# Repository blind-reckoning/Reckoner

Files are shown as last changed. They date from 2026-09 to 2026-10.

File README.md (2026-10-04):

<p align="center">
  <picture>
    <source media="(prefers-color-scheme: dark)" srcset="brand/logos/lockup-reversed.svg">
    Blind Reckoning
  </picture>
</p>

<p align="center">
  <strong>Turns press-and-hold motorised blinds into Home Assistant covers.</strong><br>
  One Reckoner per blind, hidden in the wall box behind the buttons you already have.
</p>

<p align="center">
  
  
  
  
  
  
  
</p>

> [!CAUTION]
> **This project switches 230 VAC mains, and its electronics are not isolated from the mains.** There is no transformer: every part of the board, including the microcontroller, the LED and the programming pads, sits at mains voltage whenever it is connected.
>
> A mistake while building, testing, flashing or installing it can **kill you** or **start a fire inside your wall**. Read the whole [Safety](#safety) section before you build, power or install anything.
>
> **If you are not qualified to work on mains wiring, do not build or install this.** Read it, learn from it, but leave the wall to an electrician.

## What it does

Motorised blinds with press-and-hold buttons have no idea where they are. The Reckoner sits in the wall box between those buttons and the blind motor, and adds what the buttons can't.

- **Keeps your buttons working, with or without Wi-Fi.** One press runs the blind all the way up or down. Another press while it is moving stops it.
- **For Home Assistant.** The blind appears as a cover: open, close, stop, set position and report position.
- **Always knows where the blind is.** There is no position sensor. It works the position out by **dead reckoning**, the way navigators did before GPS: from a known starting point, the calibrated time for a full stroke and the time elapsed.
- **Takes a fix at every end.** When the blind reaches fully open or fully closed, the motor's own limit switch cuts its current. The Reckoner sees that drop and takes a **fix** (position confirmed), which clears any **drift** (timing error built up since the last fix).
- **Keeps its position through power cuts.** It notices mains loss within one cycle and saves the position on the energy left in its capacitors.
- **Fits behind the switches.** The board is 70 × 54.5 mm, sized for an Italian 503 wall box.

Positions are whole percent: 0% is closed and 100% is open, matching Home Assistant.

## How it works

Every movement now goes through the Reckoner, so the blind can't move without it knowing.

| Block | Main parts | What it does |
|---|---|---|
| Mains input | 2 A slow-blow fuse, 275 VAC varistor | Protects the board and the wall wiring; circuit ground is mains L after the fuse |
| Off-line 5 V supply | LNK3206D high-side buck | Makes 5 V straight from the mains, with no transformer, and keeps running for at least 100 ms after a power cut |
| 3.3 V regulator | AP2112K-3.3 | Clean 3.3 V for the radio and the metering chip |
| Microcontroller | ESP32-C6-MINI-1 | Wi-Fi 6, Bluetooth LE and Thread; runs the dead-reckoning logic |
| Metering | HLW8110, 10 mΩ shunt | Measures motor current (to detect the ends) and mains voltage |
| Motor relays | HF46F-G on/off, G5Q-14 changeover | Switches the motor, interlocked in hardware |
| Button and mains sense | resistor dividers, BAT54S clamps | Reads the wall buttons and every mains cycle, without optocouplers |
| Programming pads | 13 test pads | First flash only, with mains disconnected; updates after that go over the air |

<p align="center">
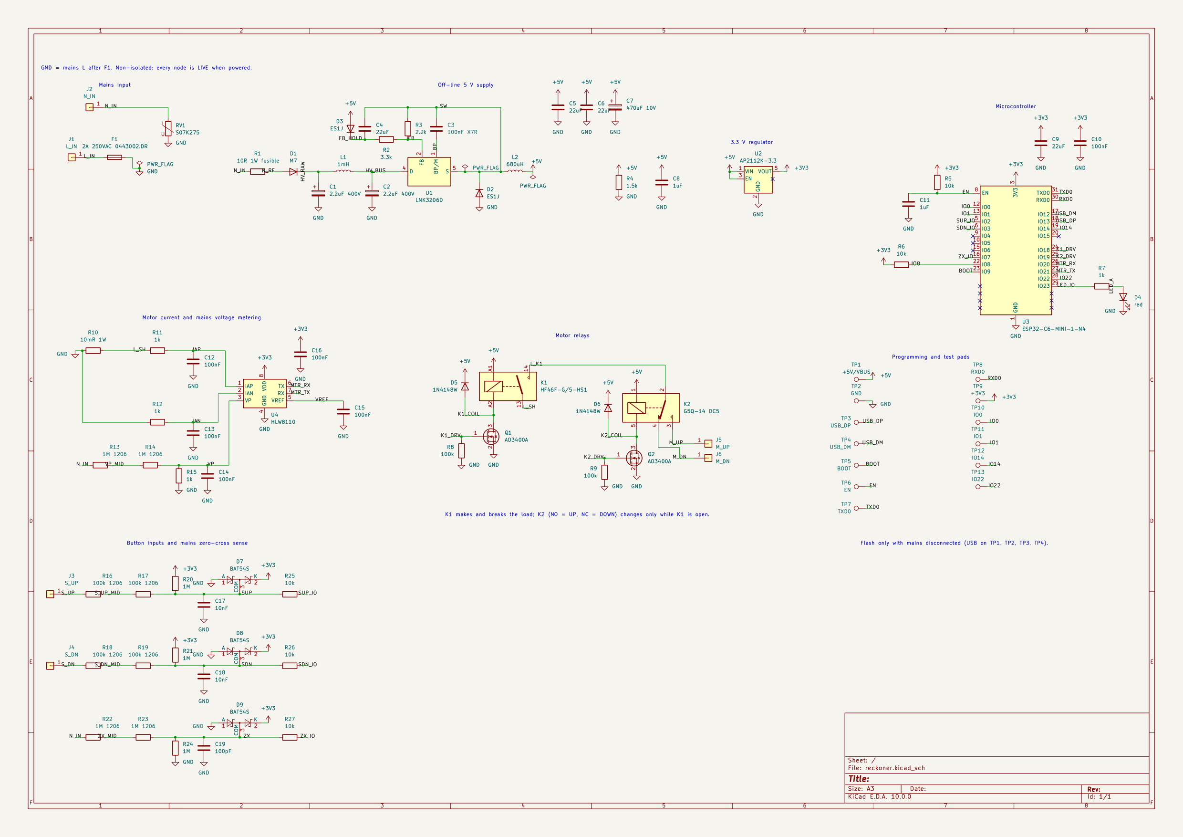
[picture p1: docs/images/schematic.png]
The full Reckoner schematic
  
</p>

### The interlock

<p align="center">
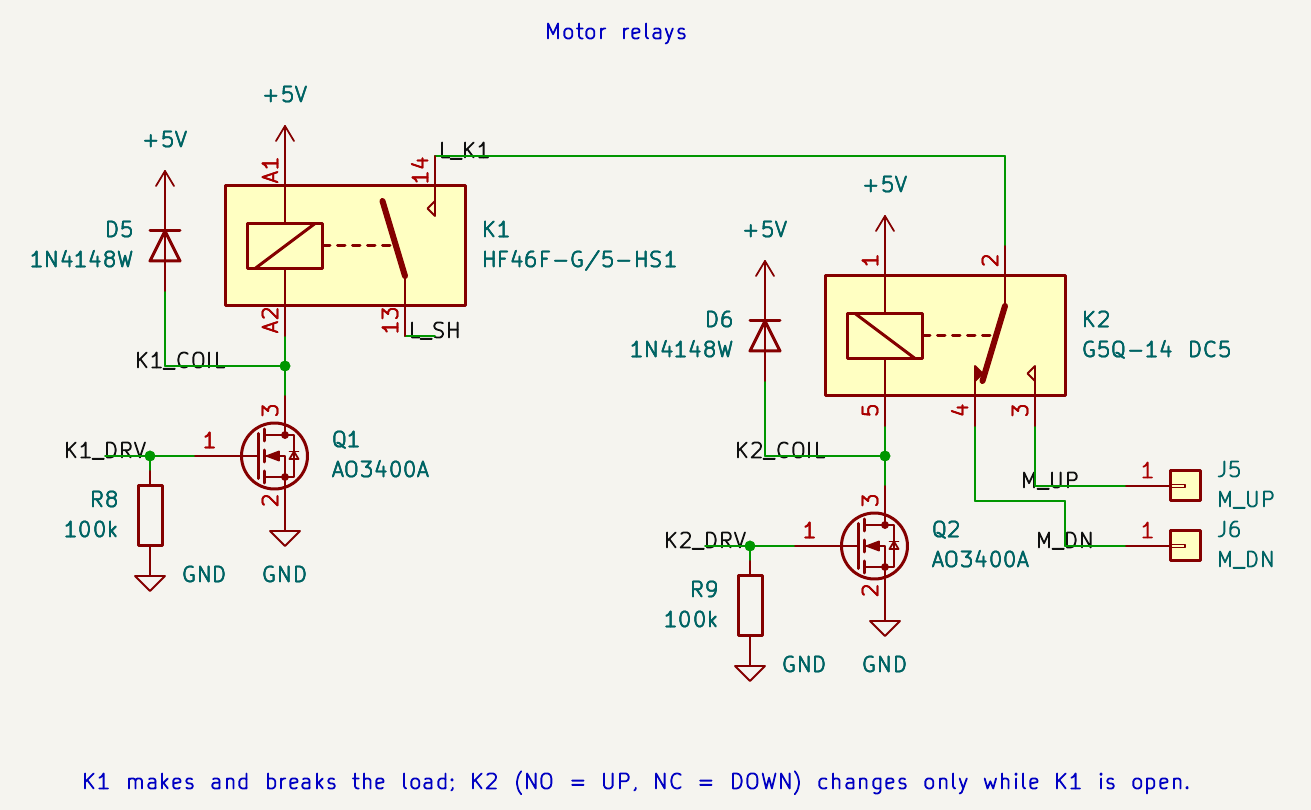
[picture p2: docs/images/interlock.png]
Motor relay block: K1 on/off feeding K2 changeover
  
</p>

K1 is the only relay that switches the motor on and off. K2 only chooses the direction, and its common contact is fed **through** K1. A changeover contact can only ever touch one side, so **up and down can never be live at the same time**: not with a firmware bug, not with a crash, not even with a welded contact.

| K1 | K2 | Motor |
|---|---|---|
| off | either | stopped |
| on | off | down |
| on | on | up |

The firmware sets K2 first and then closes K1, and opens K1 before releasing K2, so K2 never switches under load. Both relay drivers are held off by hardware through reset, boot, crashes and flashing.

### The board

<p align="center">
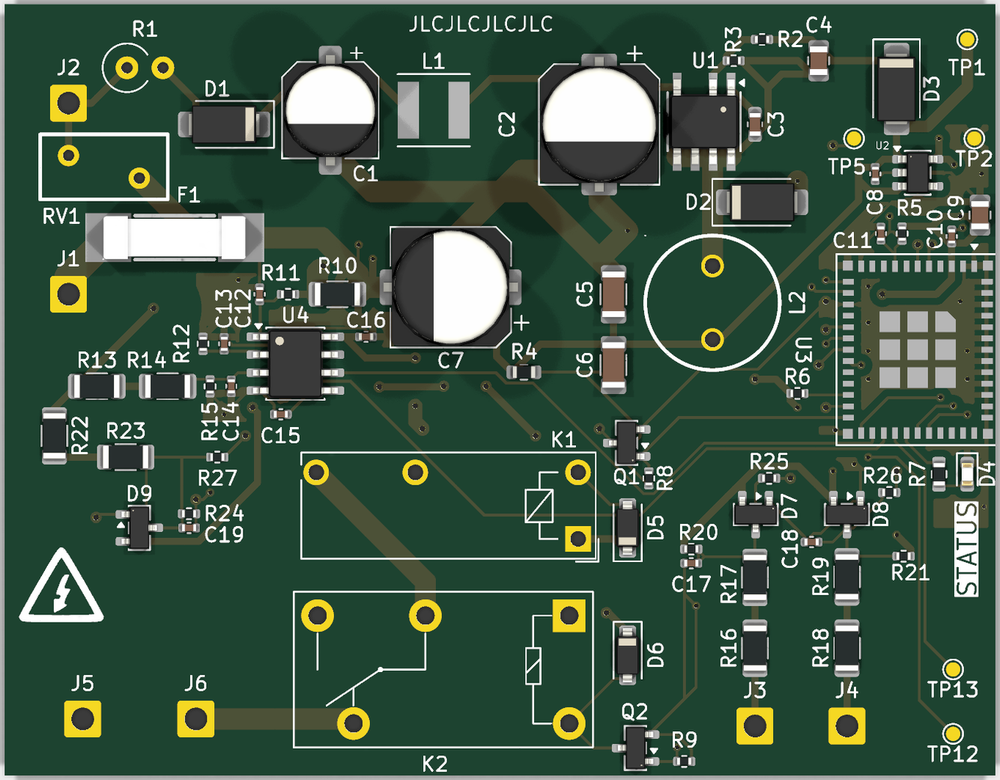
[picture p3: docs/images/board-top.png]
The routed Reckoner, top side
  
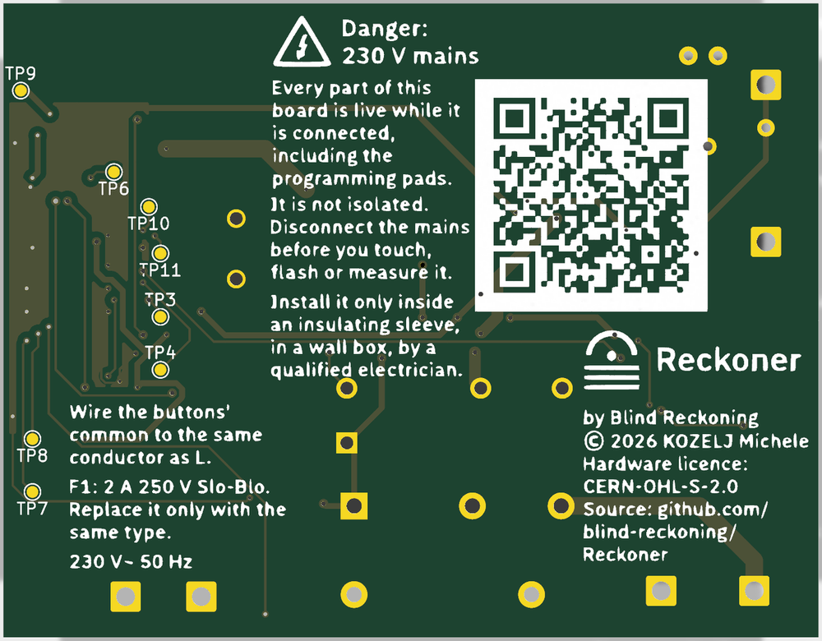
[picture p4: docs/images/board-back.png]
The Reckoner, back side: mains warnings, licence and a QR code to this repository
  
</p>

The board is 70 × 54.5 mm on two layers, placed and routed by hand. Custom design rules keep the mains nodes 3 to 5 mm apart, and 5 mm around the motor wires. The back carries the mains warnings, the licence and a QR code to this repository. The Gerbers, drill and placement files for JLCPCB are in [`PCB/production/`](PCB/production/).

## Safety

### Why this board is more dangerous than most

> [!WARNING]
> **There is no low-voltage side.** Circuit ground is **mains live (L)**. The ESP32, its antenna, the LED, the MOSFETs, the test pads and every copper trace sit at 230 VAC relative to earth whenever L and N are connected. There is no protective earth connection, so all protection from shock comes from the enclosure.

- **"Off" is not safe.** The board is powered as long as L and N are connected. A blind that is stopped, relays that are open or a "power off" in an app change nothing. Only isolating the circuit at the breaker does.
- **The motor wires are dangerous even when idle.** J5 and J6 connect to neutral through the motor windings when the relays are open. While the motor runs, its run capacitor puts about **460 VAC** between the up and down wires.
- **It can stay charged after you unplug it.** The two 400 V capacitors (C1 and C2) can hold a dangerous charge after mains is removed. Measure across them before you touch a board that has been powered.

### Never

> [!CAUTION]
> - **Never connect a USB cable, USB-serial adapter, debugger or laptop while the board is connected to mains.** A computer's USB ground is usually tied to earth through its charger. Joining it to this board's ground, which is mains L, shorts L to earth through your cable and your computer, and can make the computer's metal parts live.
> - **Never use a grounded oscilloscope probe or a mains-powered instrument on a live board.** Same reason, same result.
> - **Never touch the board while it is connected to mains**, not even "just the logic side". There is no logic side. There is only the death side!
> - **Never power it without an insulating enclosure**, and never mount it in a metal box or anywhere it can touch other conductors.
> - **Never work on live mains alone.** Always have a person capable, trained and willing of providing first aid.

### Before you install

1. **Get a qualified electrician.** In many countries, Italy included, work on fixed household wiring must be done by a qualified installer. An uncertified device in your wiring may also affect your home insurance. Check your local rules.
2. **Isolate and prove dead.** Switch off the circuit at the breaker, lock it off, and check with a voltage tester that you have just checked on a known live source. Check the tester again afterwards.
3. **Check the upstream protection.** The circuit must have a breaker of 16 A or less (with at least 6 kA breaking capacity) and a 30 mA RCD. The board's fuse handles overloads only: with its 50 A breaking capacity it relies on the house breaker to clear a direct short.
4. **Wire it exactly as labelled.**
   - J1 goes to live (L) and J2 to neutral (N). Swapping them is not supported.
   - The wall buttons' common must be on the **same L conductor** as J1.
   - J3 and J4 go to the up and down button outputs, and J5 and J6 to the motor's up and down wires.
   - The motor's neutral stays on house N in the box; it never goes to the board.
5. **Use the right materials.** The leads are 0.75 mm² H05V-K wire rated 450/750 V. Join them with lever connectors rated for the circuit, and keep the insulated board clear of the other cables in the box.
6. **Check the motor.** It must be a 230 VAC capacitor-run tubular motor of about 1 A, with two direction wires and **its own end-of-travel limit switches**. The Reckoner relies on those switches to stop at the ends. Don't connect anything larger: the direction relay is rated 3 A at 250 VAC.

### Flashing and bench testing

- **Flash only with mains disconnected at the source**, never just switched off at the wall. The first flash uses the USB pads TP1 to TP4. Short TP5 (BOOT) to GND during reset to enter download mode. After that, updates go over the air. The first-flash procedure hasn't been tried on hardware yet.
- **Live testing belongs on an isolated bench:**
  - power it through an isolation transformer;
  - use a current-limited supply, such as a series-lamp limiter, for the first power-up;
  - keep a clear shield in front of the board and your hands away from it;
  - measure only with isolated or differential probes.
- **An isolation transformer doesn't make the board safe to touch.** It only removes the earth reference.

### What the board does to protect you, and what it doesn't

| It does | It doesn't |
|---|---|
| A 2 A slow-blow fuse on L, a 10 Ω fusible resistor in front of the supply and a 275 VAC varistor against surges | Isolate anything: there is no transformer, no earth and no touch protection on the board |
| Have a hardware interlock: up and down can never both be live | Clear a direct short by itself: that is the house breaker's job |
| Have relays that default to off through reset, boot, crashes and flashing | Make "off" safe: the board is live while L and N are connected |
| Have button inputs that tolerate a common wired to N (at most 1.6 mA flows, and the firmware can flag it) | Replace an enclosure, an RCD or a qualified installer |
| Have a layout that keeps mains nodes 3 to 5 mm apart, and 5 mm around the motor wires, except between a part's own pins | Carry any certification: no CE marking, no UL listing, no lab testing |

### Disclaimer

> [!IMPORTANT]
> Blind Reckoning is a hobby prototype I built for Hack Club Half Life. It is **not a certified product** and has **not been tested by any laboratory**. Everything in this repository is provided as is, without warranty of any kind.
>
> **If you build, flash, test or install a Reckoner, you do so entirely at your own risk.** The authors accept no responsibility for injury, death, fire or damage to property caused by using anything in this repository.
>
> The **Blind Reckoning** "brand" is just a game. Please don not take it too seriously ;)

## Project status

| Stage | State |
|---|---|
| Requirements and architecture | done |
| Parts list (`BOM/bom.csv`, JLCPCB/LCSC parts) | done |
| Schematic: 86 parts, 51 nets, 0 ERC errors | done |
| PCB layout: 70 × 54.5 mm, two layers | done |
| Production files for JLCPCB (`PCB/production/`) | done |
| Order costed: 5 PCBs, a stencil and parts for one board (`bom.csv`) | done |
| Ordering boards and parts | next |
| Enclosure | not started |
| Firmware | not started |

## Repository

```
PCB/            KiCad 10 project: schematic, board, custom symbols and footprints
PCB/production/ Gerbers, drill and placement files for JLCPCB
CAD/            enclosure and 3D assembly (to come)
Firmware/       firmware (to come)
brand/          logos, colours and fonts
docs/images/    images used in this README
BOM/            bill of materials (bom.csv, ready for JLCPCB assembly), ordering lists and supplier quotes
bom.csv         order cost: PCBs, stencil, parts, shipping and taxes
LICENSE         hardware licence: CERN-OHL-S-2.0
LICENSE-DOCS    documentation licence: CC BY-SA 4.0
```

## Licence

Blind Reckoning is open hardware. You may study, build, modify, share and sell it under these terms:

| What | Licence | Full text |
|---|---|---|
| **Hardware:** everything in `PCB/` and `CAD/`, and `BOM/bom.csv` | CERN Open Hardware Licence version 2, strongly reciprocal (**CERN-OHL-S-2.0**) | [`LICENSE`](LICENSE) |
| **Documentation:** this README and everything in `docs/` | Creative Commons Attribution-ShareAlike 4.0 International (**CC BY-SA 4.0**) | [`LICENSE-DOCS`](LICENSE-DOCS) |
| **Firmware** | Not written yet; its licence will be chosen when it is. | |

**These licences apply retroactively.** They cover every version of this repository, including all commits made before the licence files were added on 2 October 2026. Any copy of the hardware or documentation you obtained from this repository, from any commit, is licensed under the terms above as if the licence files had been there from the first commit.

**Strongly reciprocal** means that if you share a modified Reckoner design, or make and sell boards based on one, you must publish your modified design under the same licence. For a mains device, this keeps every change, including the safety-relevant ones, open to review.

Hardware notice:

```
Copyright 2026 KOZELJ Michele

This source describes Open Hardware and is licensed under the CERN-OHL-S v2.

You may redistribute and modify this source and make products using it under
the terms of the CERN-OHL-S v2 (https://ohwr.org/cern_ohl_s_v2.txt).

This source is distributed WITHOUT ANY EXPRESS OR IMPLIED WARRANTY, INCLUDING
OF MERCHANTABILITY, SATISFACTORY QUALITY AND FITNESS FOR A PARTICULAR PURPOSE.
Please see the CERN-OHL-S v2 for applicable conditions.

Source location: https://github.com/blind-reckoning/Reckoner

As per CERN-OHL-S v2 section 4, should You produce hardware based on this
source, You must where practicable maintain the Source Location visible on
the circuit board or enclosure of the Reckoner or other products you make
using this source.
```

Not covered by these licences:

- **The Blind Reckoning name and logos** (`brand/logos/`, `brand/symbols/`) are not licensed for reuse. Modified or cloned hardware must use its own name and mark. You may say it is "for Blind Reckoning" or "compatible with Blind Reckoning" (see the [brand book](brand/README.md)).
- **The fonts** in `brand/fonts/` (IBM Plex Sans, IBM Plex Mono, Young Serif) belong to their authors and are distributed under the SIL Open Font License 1.1. Their licence files are next to them.
- **KiCad library symbols and footprints** used in the design are under KiCad's library licence (CC BY-SA 4.0 with an exception for designs that use them), so they don't change the licence of the Reckoner design.

## Built for

[Hack Club Half Life](https://halflife.hackclub.com), 2026.

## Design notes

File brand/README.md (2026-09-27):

# Blind Reckoning brand

The brand book for Blind Reckoning. Follow it for any UI, docs, README copy, packaging or user-facing strings.

## Files in this folder

- `tokens.css`: every color, spacing, radius and shadow token as a CSS custom property (`var(--chart)`, `var(--space-4)`), both themes, the `@font-face` rules and `.type-*` classes for the text styles. Link it and use the variables; never hard-code a hex value. Set `data-theme="night-watch"` on `<html>` to force dark, `data-theme="chart"` to force light; otherwise it follows the system setting.
- `tokens.json`: the same tokens as data, with a usage note on each.
- `fonts/`: Young Serif, IBM Plex Sans and IBM Plex Mono (SIL Open Font License).
- `logos/`: the mark, lockup and wordmark as outlined SVGs. Never redraw them.
- `symbols/`: the dead-reckoning and fix symbols.

Token names below (`chart`, `brass`, `sea`…) are the CSS variables without the `--`.

Blind Reckoning turns press-and-hold motorised blinds into Home Assistant covers. It cannot see where a blind is, so it works it out the way navigators did before GPS: from a known starting point, a known speed and the time elapsed. When the blind reaches fully open or fully closed, it takes a **fix** and clears any drift. The identity comes from the chart table: chart paper, navy ink, brass instruments and a red course line.

## Name

- Write **Blind Reckoning**: two words, both capitalised. Never "BlindReckoning", "Blind-Reckoning" or "BR" in prose.
- In code: `blind-reckoning` for the repository and packages, `blind_reckoning` for the Home Assistant integration domain.
- The hardware unit is a **Reckoner**: "fit one Reckoner per blind".
- Say "for Home Assistant". Never put "Home Assistant" in the name, the mark or a product title.
- Other people's work says "for Blind Reckoning" or "compatible with Blind Reckoning". Forks and clones that change the firmware or hardware use their own name and mark.

## Voice

Plain, precise, quietly nautical. Say what the device is doing in one sentence, then stop.

- Use navigation words only where they mean exactly the thing (see Vocabulary). Never as decoration: no "ahoy", pirates, anchors or rope.
- Sentence case everywhere except the `label` style. No exclamation marks, no emoji.
- Talk to "you"; the device is "it".
- Seconds take one decimal and a space before the unit: "23.4 s". Positions are whole percent, 0% closed and 100% open, matching Home Assistant.

Write like this:

> Took a fix at fully open. Corrected 0.8 s of drift.

> Heave the log: run the blind fully down, then press Stop the moment it lands.

> Position is estimated. It is confirmed the next time the blind reaches an end.

Not like this: "Arr, yer blinds be smart now!", "Revolutionary AI-powered shading."

## Vocabulary

| Term | Means | In the UI |
| --- | --- | --- |
| Fix | Position confirmed at an endstop | "Last fix: fully open, 2 h ago" |
| Drift | Timing error built up since the last fix | "Drift ±1.2 s" |
| DR position | Position estimated from elapsed time | "41% (estimated)" |
| Heave the log | The calibration run that times a full stroke | "Heave the log" button in setup |
| Heading | Direction of travel | "Heading up" |

The first time a term appears on a screen, put the plain meaning beside it.

## Logo

The mark is a semicircle and dot, the navigator's plotting symbol for a dead-reckoning position, rising over three slats. It also reads as a sun on the horizon, which is what blinds are for.

- `mark.svg` (brass arc, ink slats) on `chart` and `chart-raised`.
- `mark-reversed.svg` on the Night watch `chart` and on any `deep` fill.
- `mark-ink.svg` for one-colour print; `mark-white.svg` for PCB silkscreen and laser etching.
- `lockup.svg` / `lockup-reversed.svg` where the name must travel with the mark (README header, packaging, the device web page). `wordmark.svg` alone only where the mark already appears nearby.
- Clear space: a quarter of the mark's height on every side. Minimum size: mark 24 px (6 mm printed), lockup 120 px wide.
- Don't recolour it beyond these versions, rotate it, outline it, add compass needles, ships or anchors, or retype the wordmark in another face.

## Color

Two themes share every token name: **Chart** by day and **Night watch** by night.

- Ground is `chart`; panels are `chart-raised`; text is `ink`, secondary text `ink-muted`. `rule` is for decorative dividers only.
- `brass` is the identity: the mark, highlights and the drift state. Keep it to roughly a tenth of any screen. Brass words use `brass-text`, on `brass-soft` when tinted.
- `deep` with `on-deep` for the header band, hero panels and the primary button.
- States: a fix is `sea` with the Fix symbol; drift is `brass` with the word "drift"; a fault or Stop is `course`. Never carry a state by colour alone.
- Keyboard focus is the `focus-ring` shadow: a 2 px gap in the ground colour, then 2 px of solid `sea`.

## Type

- `display` (Young Serif) for page titles and the wordmark only. Never in device UI, never below 24 px.
- `heading`, `body` and `label` (IBM Plex Sans) for everything people read. `label` is set in capitals.
- `reading` (IBM Plex Mono) for the instrument readout: current position and travel time. `code` for entity IDs, YAML and firmware values.
- All three families are under the SIL Open Font License, so the firmware's web page can bundle them.

## Symbols

- `dr-position.svg`, a semicircle and dot on a baseline: position estimated by timing.
- `fix.svg`, a circle and dot: position confirmed at an endstop.
- Both are 24 px with a 2 px stroke, drawn in `ink`; always set a word beside them.
- For every other icon use Material Design Icons (`mdi:blinds`, `mdi:arrow-up`, `mdi:stop`), the set Home Assistant already uses, so the device page and the dashboard match.

## Imagery

Line drawings on chart paper: timing diagrams, the slat stack, a plotted course from open to closed. Photos show real installs in daylight and the hardware on a workbench. No stock oceans, ships or brass compasses as decoration; the metaphor lives in the words and the mark.

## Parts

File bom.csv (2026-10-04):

Item | Quantity | Supplier | Price (USD) | Note
Bill of materials (reference only) | 1 | N/A | 0.00 | The per-part BOM is BOM/bom.csv. Orders: BOM/bom-lcsc.csv (LCSC) and BOM/bom-digikey.csv (Digi-Key). Quote screenshots are in BOM/.
PCB: 2 layers, 70 × 54.5 mm, 1.6 mm, green, lead-free HASL | 1 | JLCPCB | 6.25 | 5 units included
SMT stencil, top side, with frame | 1 | JLCPCB | 16.75
LCSC parts | 1 | LCSC | 29.24 | Order quantities include LCSC minimum orders.
DigiKey parts | 1 | Digi-Key | 4.77
Shipping and taxes |  | All | 89.74 | JLCPCB $24.28 (shipping $34.28 - $10.00 coupon). LCSC $30.17 (shipping $12.88 + tax $20.34 - $3.05 of discounts). Digi-Key $35.29 (€25.00 shipping + €6.44 VAT).
Total |  |  | 146.75 | Items $57.01, shipping and taxes $89.74.

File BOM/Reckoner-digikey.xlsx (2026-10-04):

Country of Origin may be different at time of shipment.
The HTSUS and ECCN information shown is for informational purposes only and is not a representation or warranty as to the accuracy or reliability of these classifications. All information is provided "as is" and is subject to change without notice. Any use made of the information provided is without recourse to Digi-Key and at the user's risk.
Index | Manufacturer Part Number | Manufacturer Name | Description | Lead Time | Availability | Stock Status | Attrition % | Requested Quantity 1 | Pack Quantity 1 | Pack Type 1 | Digi-Key Part Number 1 | Unit Price 1 | Extended Price 1 | Minimum Order Quantity 1 | Customer Reference | Requested Part Number | Lead Weeks | Datasheet | Reference Designator | US Import Tariff | Note | Part Status | RoHS Status | REACH Status | Moisture Sensitivity Level (MSL) | ECCN | HTSUS | Country of Origin | Environmental Information | Original Part numbers | Unit of Measure | Image | Product Notes
1 |  |  |  |  |  |  |  |  |  |  |  |  |  |  |  | Digi-Key Part Number | N/A |  | Reference Designator |  | Note |  | - | - |  | - | - | - |  | Digi-Key Part Number |  |  | This entry does not match a product carried by DigiKey and cannot be quoted.
2 | ESP32-C6-MINI-1-N4 | Espressif Systems | RF TXRX MOD BT WIFI PCB TH SMD |  | 190 | In Stock |  | 1 | 1 | Cut Tape (CT) | 1965-ESP32-C6-MINI-1-N4CT-ND | 3.98000 | €3.98 | 1 |  | 1965-ESP32-C6-MINI-1-N4CT-ND | 8 | https://www.espressif.com/sites/default/files/documentation/esp32-c6-mini-1_mini-1u_datasheet_en.pdf | U3 | N/A | Same part; backordered at LCSC. | Active | Unknown |  | 3 (168 Hours) | 5A992C SC | 8517.62.0090 | Taiwan |  | 1965-ESP32-C6-MINI-1-N4CT-ND | Each | https://mm.digikey.com/Volume0/opasdata/d220001/medias/images/4908/MFG_ESP32-C6-MINI-1-N4.jpg
3 | RC0402FR-071KL | YAGEO | RES 1K OHM 1% 1/16W 0402 |  | 4,297,806 | In Stock |  | 3 | 3 | Cut Tape (CT) | 311-1.00KLRCT-ND | 0.09000 | €0.27 | 1 |  | 311-1.00KLRCT-ND | 22 | https://yageogroup.com/content/datasheet/asset/file/PYU-RC_GROUP_51_ROHS_L | R11,R12,R15 | N/A | Same spec as the UNI-ROYAL part, which is backordered at LCSC. | Active | ROHS3 Compliant | REACH Unaffected | 1 (Unlimited) | EAR99 | 8533.21.0030 | Taiwan | https://www.yageogroup.com/content/Resource%20Library/Product%20Environmental%20Compliance/RoHS_Compliance_YAGEO.pdf | 311-1.00KLRCT-ND | Each | https://mm.digikey.com/Volume0/opasdata/d220001/derivates/6/003/121/213/cut-tape-render_web%28640x640%29.jpg

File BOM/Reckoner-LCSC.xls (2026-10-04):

Reckoner-LCSC |  |  |  |  |  |  |  |  |  | LCSC BOM Quotation
 |  |  |  |  |  |  |  |  |  | BOM Date Created：04/10/26 20:34:16 |  |  |  | BOM Export Date: 04/10/26 20:36:48 |  |  |  | The matching result is a real-time query result, availability and prices may fluctuate. Backorder items are estimated prices for your reference, please submit "Create Quote" to get the real price. All information is provided "as is" and is subject to change without notice. Any use made of the information provided is without recourse to LCSC and at the user's risk.
 |  |  |  |  |  |  |  |  |  | EST TOTAL :$29.19 |  |  |  | Website：https://www.lcsc.com/bom | https://www.lcsc.com/bom | https://www.lcsc.com/bom | https://www.lcsc.com/bom
Uploaded data |  |  |  |  |  |  |  |  |  | LCSC Matching Results
LCSC# | Mfr. | Mrf# | Description | Package | Value | Customer Part Number | Quantity | Target Price(USD) | Target Lead Time(Business Days) | Mrf# | Mfr. | Order Qty. | Unit Price(USD) | Ext.Price(USD) | LCSC# | Package | Min | Mult | SPQ | Availability | Stock Status | Customer Notes | Description | Matched status | Product Link
C187538 | Littelfuse | 0443002.DR | Littelfuse 0443002.DR, 2 A Slo-Blo | FUSE-SMD_L10.1-W3.1 |  | - | 1 |  |  | 0443002.DR | Littelfuse | 1 | 0.8063 | 0.81 | C187538 | SMD,10.1x3.1mm | 1 | 1 | 1500 | 1892 | In Stock |  | 2A 250V Fuse Surface Mount 10.1x3.1mm | Exact Matches | https://www.lcsc.com/product-detail/C187538.html
C1527389 | TDK | B72207S2271K101 | TDK B72207S2271K101 (S07K275) | RES-TH_L9.0-W4.6-P5.00-D0.6-S1.60 |  | - | 1 |  |  | B72207S2271K101 | TDK | 5 | 0.0815 | 0.41 | C1527389 | Through Hole | 5 | 5 | 1000 | 2570 | In Stock |  | 710V 350V 275V 430V Through Hole Varistors, MOVs RoHS | Exact Matches | https://www.lcsc.com/product-detail/C1527389.html
C145951 | CCO(Chian Chia Elec) | FR1WS-10Ω±5% T | FR1WS 10 Ω fusible | R_Axial_DIN0309_L9.0mm_D3.2mm_P2.54mm_Vertical |  | - | 1 |  |  | FR1WS-10Ω±5% T | CCO(Chian Chia Elec) | 20 | 0.0373 | 0.75 | C145951 | Through Hole,D3.2xL9mm | 20 | 20 | 2000 | 3100 | In Stock |  | 10Ω 1W 250V Fuse Resistor ±200ppm/℃ ±5% Through Hole,D3.2xL9mm Through Hole Resistors RoHS | Exact Matches | https://www.lcsc.com/product-detail/C145951.html
C95872 | MDD(Microdiode Semiconductor) | M7 | M7 | D_SMA |  | - | 1 |  |  | M7 | MDD(Microdiode Semiconductor) | 100 | 0.0103 | 1.03 | C95872 | SMA(DO-214AC) | 100 | 100 | 5000 | 1908900 | In Stock |  | Diode Independent 1kV 1A Surface Mount SMA(DO-214AC) | Exact Matches | https://www.lcsc.com/product-detail/C95872.html
C48970947 | Honor Elec | RYUD400V2.2UF6*10 | 2.2 µF, RYUD400V2.2UF6*10 | CP_Elec_6.3x9.9 |  | - | 1 |  |  | RYUD400V2.2UF6*10 | Honor Elec | 10 | 0.0797 | 0.80 | C48970947 | SMD,D6.3xL10.2mm | 10 | 10 | 700 | 620 | In Stock |  | 400V ±20% 2.2uF SMD,D6.3xL10.2mm Aluminum Electrolytic Capacitors RoHS | Exact Matches | https://www.lcsc.com/product-detail/C48970947.html
C33129636 | FOLLON | EFVD400ADA3R9M08B0 | 3.9 µF, FOLLON EFVD400ADA3R9M08B0 | CP_Elec_8x10 |  | - | 1 |  |  | EFVD400ADA3R9M08B0 | FOLLON | 5 | 0.1372 | 0.69 | C33129636 | SMD,D8xL10.5mm | 5 | 5 | 500 | 440 | In Stock |  | 3.9uF ±20% 400V Aluminum Electrolytic Capacitors | Exact Matches | https://www.lcsc.com/product-detail/C33129636.html
C5339706 | XR | XRNR5040-1mH/M | 1 mH, XRNR5040-1mH/M | L_Taiyo-Yuden_NR-50xx |  | - | 1 |  |  | XRNR5040-1mH/M | XR | 10 | 0.0589 | 0.59 | C5339706 | SMD,5x5mm | 10 | 10 | 1500 | 630 | In Stock |  | 250mA 1mH ±20% 6.2Ω 250mA Magnetic Shielded Inductor SMD,5x5mm Fixed Inductors | Exact Matches | https://www.lcsc.com/product-detail/C5339706.html
C2987730 | POWER INTEGRATIONS | LNK3206D-TL | LNK3206D-TL | PowerIntegrations_SO-8C |  | - | 1 |  |  | LNK3206D-TL | POWER INTEGRATIONS | 1 | 1.0874 | 1.09 | C2987730 | SO-7 | 1 | 1 | 2500 | 430 | In Stock |  | 360mA 66kHz 725V Buck-Boost SO-7 AC DC Converters, Offline Switchers RoHS | Exact Matches | https://www.lcsc.com/product-detail/C2987730.html
C14663 | YAGEO | CC0603KRX7R9BB104 | 100 nF X7R | C_0603_1608Metric |  | - | 1 |  |  | CC0603KRX7R9BB104 | YAGEO | 50 | 0.0124 | 0.62 | C14663 | 0603 | 50 | 50 | 4000 | 5108800 | In Stock |  | 100nF ±10% 50V Ceramic Capacitor X7R 0603 | Exact Matches | https://www.lcsc.com/product-detail/C14663.html
C86560 | MCC | ES1J-LTP | ES1J-LTP | D_SMA |  | - | 2 |  |  | ES1J-LTP | MCC | 20 | 0.0511 | 1.02 | C86560 | SMA(DO-214AC) | 20 | 20 | 5000 | 10040 | In Stock |  | 35ns 600V 1.7V@1A 1A SMA(DO-214AC) Single Diodes RoHS | Exact Matches | https://www.lcsc.com/product-detail/C86560.html
C2924238 | PROD Tech | PDPTAT0810-681K | 680 µH, PDPTAT0810-681K | IND-TH_BD9.5-P5.20-D0.6 |  | - | 1 |  |  | PDPTAT0810-681K | PROD Tech | 5 | 0.1168 | 0.58 | C2924238 | Through Hole,D9.5xL12mm | 5 | 5 | 250 | 2345 | In Stock |  | 350mA 680uH ±10% 800mA 910mΩ Drum-core inductor Through Hole,D9.5xL12mm Fixed Inductors | Exact Matches | https://www.lcsc.com/product-detail/C2924238.html
C45783 | Samsung Electro-Mechanics | CL21A226MAQNNNE | 22 µF X5R | C_0805_2012Metric |  | - | 2 |  |  | CL21A226MAQNNNE | Samsung Electro-Mechanics | 20 | 0.2222 | 4.44 | C45783 | 0805 | 20 | 20 | 2000 | 1105400 | In Stock |  | 22uF ±20% 25V Ceramic Capacitor X5R 0805 | Exact Matches | https://www.lcsc.com/product-detail/C45783.html
C25890 | UNI-ROYAL | 0402WGF3301TCE | 3.3 kΩ 1 % | R_0402_1005Metric |  | - | 1 |  |  | 0402WGF3301TCE | UNI-ROYAL | 100 | 0.0036 | 0.36 | C25890 | 0402 | 100 | 100 | 10000 | 1148200 | In Stock |  | 3.3kΩ ±1% 62.5mW 0402 Thick Film Resistor | Exact Matches | https://www.lcsc.com/product-detail/C25890.html
C25879 | UNI-ROYAL | 0402WGF2201TCE | 2.2 kΩ 1 % | R_0402_1005Metric |  | - | 1 |  |  | 0402WGF2201TCE | UNI-ROYAL | 100 | 0.0013 | 0.13 | C25879 | 0402 | 100 | 100 | 10000 | 744800 | In Stock |  | 2.2kΩ ±1% 62.5mW 0402 Thick Film Resistor | Exact Matches | https://www.lcsc.com/product-detail/C25879.html
C12891 | Samsung Electro-Mechanics | CL31A226KAHNNNE | 22 µF X5R | C_1206_3216Metric |  | - | 2 |  |  | CL31A226KAHNNNE | Samsung Electro-Mechanics | 20 | 0.1751 | 3.50 | C12891 | 1206 | 20 | 20 | 2000 | 7520 | In Stock |  | 22uF ±10% 25V Ceramic Capacitor X5R 1206 | Exact Matches | https://www.lcsc.com/product-detail/C12891.html
C2693598 | SAMYOUNG | BXJ10V470UF8*10 | 470 µF, BXJ10V470UF8*10 | CP_Elec_8x10 |  | - | 1 |  |  | BXJ10V470UF8*10 | SAMYOUNG | 5 | 0.2370 | 1.19 | C2693598 | SMD,D8xL10mm | 5 | 5 | 500 | 375 | In Stock |  | 470uF ±20% 10V Aluminum Electrolytic Capacitors 5000hrs@105℃ | Exact Matches | https://www.lcsc.com/product-detail/C2693598.html
C22843 | UNI-ROYAL | 0603WAF1501T5E | 1.5 kΩ 1 % | R_0603_1608Metric |  | - | 1 |  |  | 0603WAF1501T5E | UNI-ROYAL | 100 | 0.0020 | 0.20 | C22843 | 0603 | 100 | 100 | 5000 | 3638900 | In Stock |  | 1.5kΩ ±1% 100mW 0603 Thick Film Resistor | Exact Matches | https://www.lcsc.com/product-detail/C22843.html
C51118 | DIODES | AP2112K-3.3TRG1 | AP2112K-3.3TRG1 | SOT-23-5 |  | - | 1 |  |  | AP2112K-3.3TRG1 | DIODES | 5 | 0.1726 | 0.86 | C51118 | SOT-25-5 | 5 | 5 | 3000 | 38230 | In Stock |  | 3.3V Positive Fixed SOT-25-5 Voltage Regulators - Linear, Low Drop Out (LDO) Regulators RoHS | Exact Matches | https://www.lcsc.com/product-detail/C51118.html
C52923 | Samsung Electro-Mechanics | CL05A105KA5NQNC | 1 µF X5R | C_0402_1005Metric |  | - | 2 |  |  | CL05A105KA5NQNC | Samsung Electro-Mechanics | 50 | 0.0108 | 0.54 | C52923 | 0402 | 50 | 50 | 10000 | 600000 | In Stock |  | 1uF ±10% 25V Ceramic Capacitor X5R 0402 | Exact Matches | https://www.lcsc.com/product-detail/C52923.html
C1525 | Samsung Electro-Mechanics | CL05B104KO5NNNC | 100 nF X7R | C_0402_1005Metric |  | - | 6 |  |  | CL05B104KO5NNNC | Samsung Electro-Mechanics | 100 | 0.0045 | 0.45 | C1525 | 0402 | 100 | 100 | 10000 | 9170900 | In Stock |  | 100nF ±10% 16V Ceramic Capacitor X7R 0402 | Exact Matches | https://www.lcsc.com/product-detail/C1525.html
C25744 | UNI-ROYAL | 0402WGF1002TCE | 10 kΩ 1 % | R_0402_1005Metric |  | - | 5 |  |  | 0402WGF1002TCE | UNI-ROYAL | 100 | 0.0034 | 0.34 | C25744 | 0402 | 100 | 100 | 10000 | 5329200 | In Stock |  | 10kΩ ±1% 62.5mW 0402 Thick Film Resistor | Exact Matches | https://www.lcsc.com/product-detail/C25744.html
C2286 | Hubei KENTO Elec | KT-0603R | KT-0603R red | LED_0603_1608Metric |  | - | 1 |  |  | KT-0603R | Hubei KENTO Elec | 100 | 0.0076 | 0.76 | C2286 | 0603 | 100 | 100 | 4000 | 2788300 | In Stock |  | Red 645nm LED Indication - Discrete 2.4V 0603 | Exact Matches | https://www.lcsc.com/product-detail/C2286.html
C21190 | UNI-ROYAL | 0603WAF1001T5E | 1 kΩ 1 % | R_0603_1608Metric |  | - | 1 |  |  | 0603WAF1001T5E | UNI-ROYAL | 100 | 0.0026 | 0.26 | C21190 | 0603 | 100 | 100 | 5000 | 1314800 | In Stock |  | 1kΩ ±1% 100mW 0603 Thick Film Resistor | Exact Matches | https://www.lcsc.com/product-detail/C21190.html
C165255 | HONGFA | HF46F-G/5-HS1 | Hongfa HF46F-G/5-HS1 | Relay_SPST_Omron_G5NB |  | - | 1 |  |  | HF46F-G/5-HS1 | HONGFA | 1 | 1.1947 | 1.19 | C165255 | Through Hole,20.5x7mm | 1 | 1 | 160 | 2885 | In Stock |  | Power Relay 1 Form A: 1A (SPST-NO) 5V Coil Through Hole,7x20.5mm | Exact Matches | https://www.lcsc.com/product-detail/C165255.html
C397241 | OMRON | G5Q-14 DC5 | Omron G5Q-14 DC5 | Relay_SPDT_Omron-G5Q-1 |  | - | 1 |  |  | G5Q-14 DC5 | OMRON | 1 | 1.1525 | 1.15 | C397241 | Through Hole,20x10mm | 1 | 1 | 100 | 12553 | In Stock |  | Power Relay 1 Form C: 1C (SPDT-CO) 5V Coil Through Hole,10x20mm | Exact Matches | https://www.lcsc.com/product-detail/C397241.html
C20917 | AOS | AO3400A | AO3400A | SOT-23 |  | - | 2 |  |  | AO3400A | AOS | 5 | 0.0898 | 0.45 | C20917 | SOT-23 | 5 | 5 | 3000 | 459730 | In Stock |  | N-Channel 30V Surface Mount SOT-23-3L | Exact Matches | https://www.lcsc.com/product-detail/C20917.html
C25741 | UNI-ROYAL | 0402WGF1003TCE | 100 kΩ 1 % | R_0402_1005Metric |  | - | 2 |  |  | 0402WGF1003TCE | UNI-ROYAL | 100 | 0.0025 | 0.25 | C25741 | 0402 | 100 | 100 | 10000 | 2740000 | In Stock |  | 100kΩ ±1% 62.5mW 0402 Thick Film Resistor | Exact Matches | https://www.lcsc.com/product-detail/C25741.html
C81598 | ST(Semtech) | 1N4148W | 1N4148W | D_SOD-123 |  | - | 2 |  |  | 1N4148W | ST(Semtech) | 50 | 0.0124 | 0.62 | C81598 | SOD-123 | 50 | 50 | 3000 | 3987150 | In Stock |  | Diode Independent 75V 150mA Surface Mount SOD-123 | Exact Matches | https://www.lcsc.com/product-detail/C81598.html
C105362 | PSA | FMF06FTHR010-LH | 10 mΩ 1 %, FMF06FTHR010-LH | R_1206_3216Metric |  | - | 1 |  |  | FMF06FTHR010-LH | PSA | 20 | 0.0414 | 0.83 | C105362 | 1206 | 20 | 20 | 4000 | 244280 | In Stock |  | 10mΩ ±1% 1W | Exact Matches | https://www.lcsc.com/product-detail/C105362.html
C970139 | Hiliwei Tech | HLW8110 | HLW8110 | SOIC-8_3.9x4.9mm_P1.27mm |  | - | 1 |  |  | HLW8110 | Hiliwei Tech | 1 | 0.6947 | 0.69 | C970139 | SOP-8 | 1 | 1 | 3000 | 10952 | In Stock |  | UART SOP-8 Energy Metering RoHS | Exact Matches | https://www.lcsc.com/product-detail/C970139.html
C17927 | UNI-ROYAL | 1206W4F1004T5E | 1 MΩ 1 % | R_1206_3216Metric |  | - | 4 |  |  | 1206W4F1004T5E | UNI-ROYAL | 100 | 0.0042 | 0.42 | C17927 | 1206 | 100 | 100 | 5000 | 3835100 | In Stock |  | 1MΩ ±1% 250mW 1206 Thick Film Resistor | Exact Matches | https://www.lcsc.com/product-detail/C17927.html
C17900 | UNI-ROYAL | 1206W4F1003T5E | 100 kΩ 1 % | R_1206_3216Metric |  | - | 4 |  |  | 1206W4F1003T5E | UNI-ROYAL | 50 | 0.0103 | 0.52 | C17900 | 1206 | 50 | 50 | 5000 | 832100 | In Stock |  | 100kΩ ±1% 250mW 1206 Thick Film Resistor | Exact Matches | https://www.lcsc.com/product-detail/C17900.html
C26083 | UNI-ROYAL | 0402WGF1004TCE | 1 MΩ 1 % | R_0402_1005Metric |  | - | 3 |  |  | 0402WGF1004TCE | UNI-ROYAL | 100 | 0.0026 | 0.26 | C26083 | 0402 | 100 | 100 | 10000 | 1050600 | In Stock |  | 1MΩ ±1% 62.5mW 0402 Thick Film Resistor | Exact Matches | https://www.lcsc.com/product-detail/C26083.html
C15195 | Samsung Electro-Mechanics | CL05B103KB5NNNC | 10 nF X7R | C_0402_1005Metric |  | - | 2 |  |  | CL05B103KB5NNNC | Samsung Electro-Mechanics | 100 | 0.0050 | 0.50 | C15195 | 0402 | 100 | 100 | 10000 | 568200 | In Stock |  | 10nF ±10% 50V Ceramic Capacitor X7R 0402 | Exact Matches | https://www.lcsc.com/product-detail/C15195.html
C8592 | JSCJ | BAT54S KL4 | BAT54S | SOT-23 |  | - | 3 |  |  | BAT54S KL4 | JSCJ | 20 | 0.0234 | 0.47 | C8592 | SOT-23 | 20 | 20 | 3000 | 165740 | In Stock |  | Diode 30V 200mA Surface Mount SOT-23 | Exact Matches | https://www.lcsc.com/product-detail/C8592.html
C1546 | FH | 0402CG101J500NT | 100 pF C0G | C_0402_1005Metric |  | - | 1 |  |  | 0402CG101J500NT | FH | 100 | 0.0042 | 0.42 | C1546 | 0402 | 100 | 100 | 10000 | 1351700 | In Stock |  | 100pF ±5% 50V Ceramic Capacitor C0G 0402 | Exact Matches | https://www.lcsc.com/product-detail/C1546.html

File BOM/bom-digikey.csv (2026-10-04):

Digi-Key Part Number | Manufacturer Part Number | Manufacturer Name | Quantity | Reference Designator | Description | LCSC Part # | Note
1965-ESP32-C6-MINI-1-N4CT-ND | ESP32-C6-MINI-1-N4 | Espressif Systems | 1 | U3 | Wi-Fi 6, Bluetooth LE and 802.15.4 module, 4 MB flash | C5736265 | Same part; backordered at LCSC.
311-1.00KLRCT-ND | RC0402FR-071KL | YAGEO | 3 | R11,R12,R15 | Resistor 1 kΩ 1 %, 0402 | C11702 | Same spec as the UNI-ROYAL part, which is backordered at LCSC.

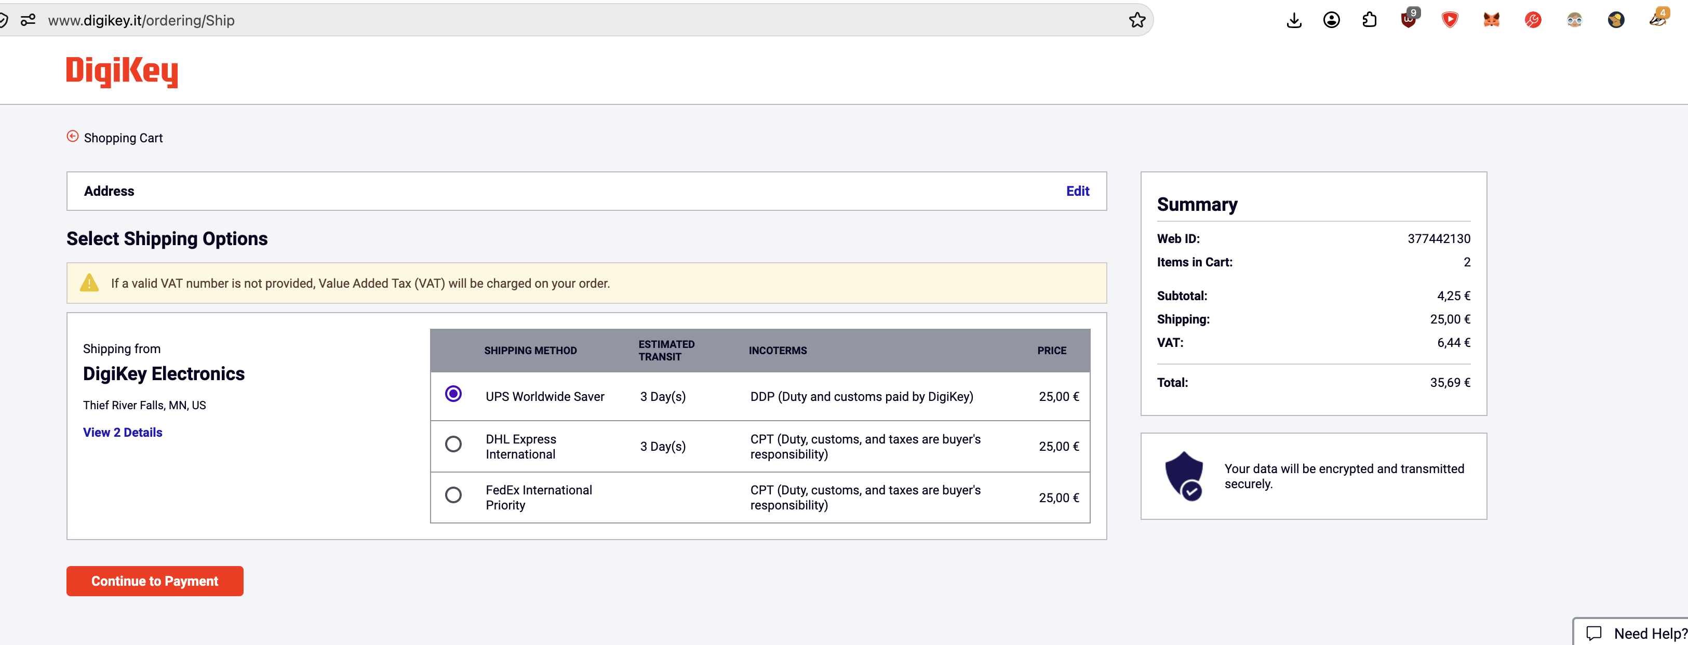
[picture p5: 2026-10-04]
BOM/DigiKey.png

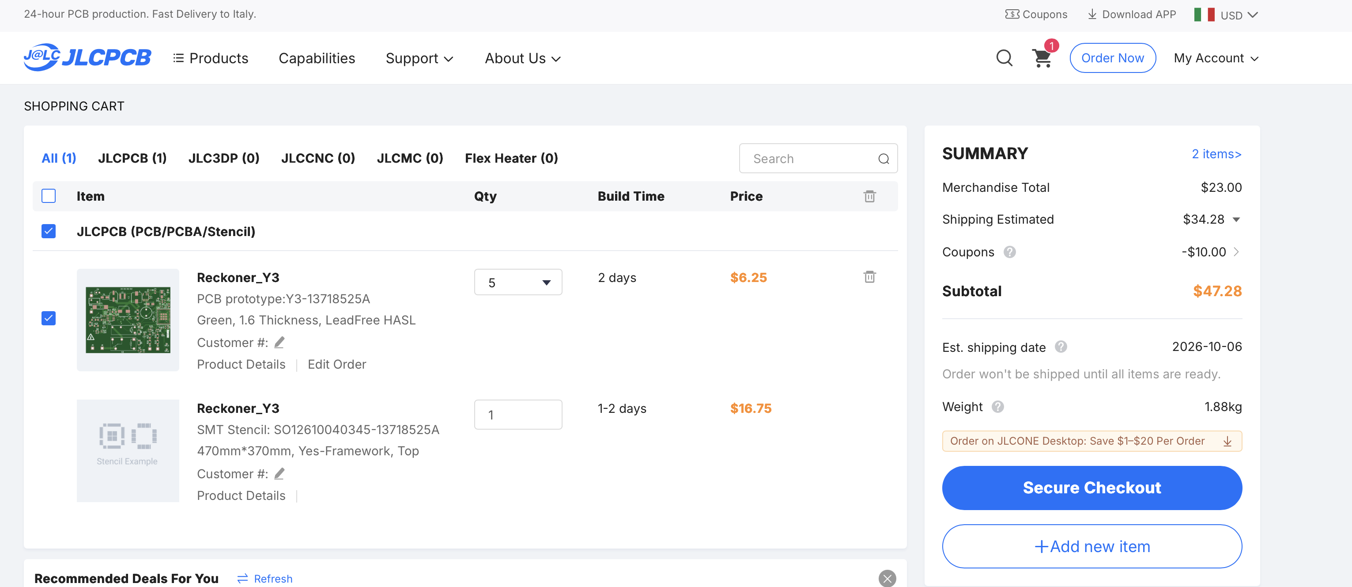
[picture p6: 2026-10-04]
BOM/JLC order.png

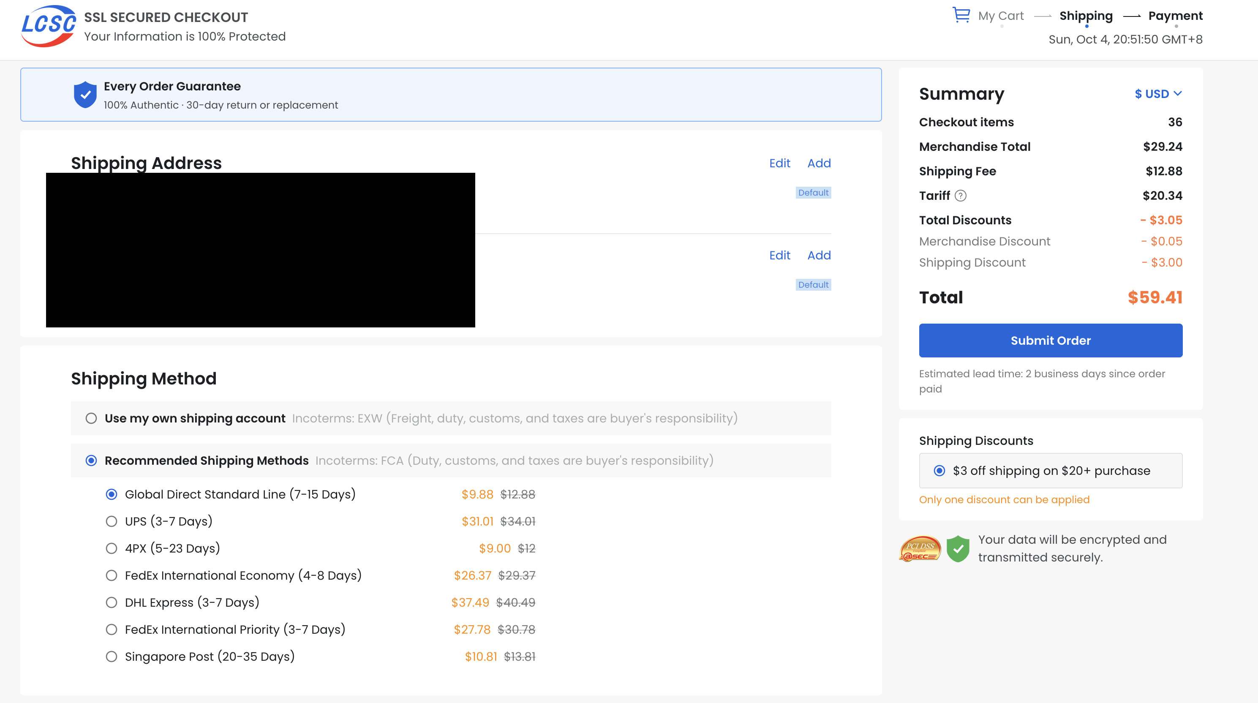
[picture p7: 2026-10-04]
BOM/LCSC.png

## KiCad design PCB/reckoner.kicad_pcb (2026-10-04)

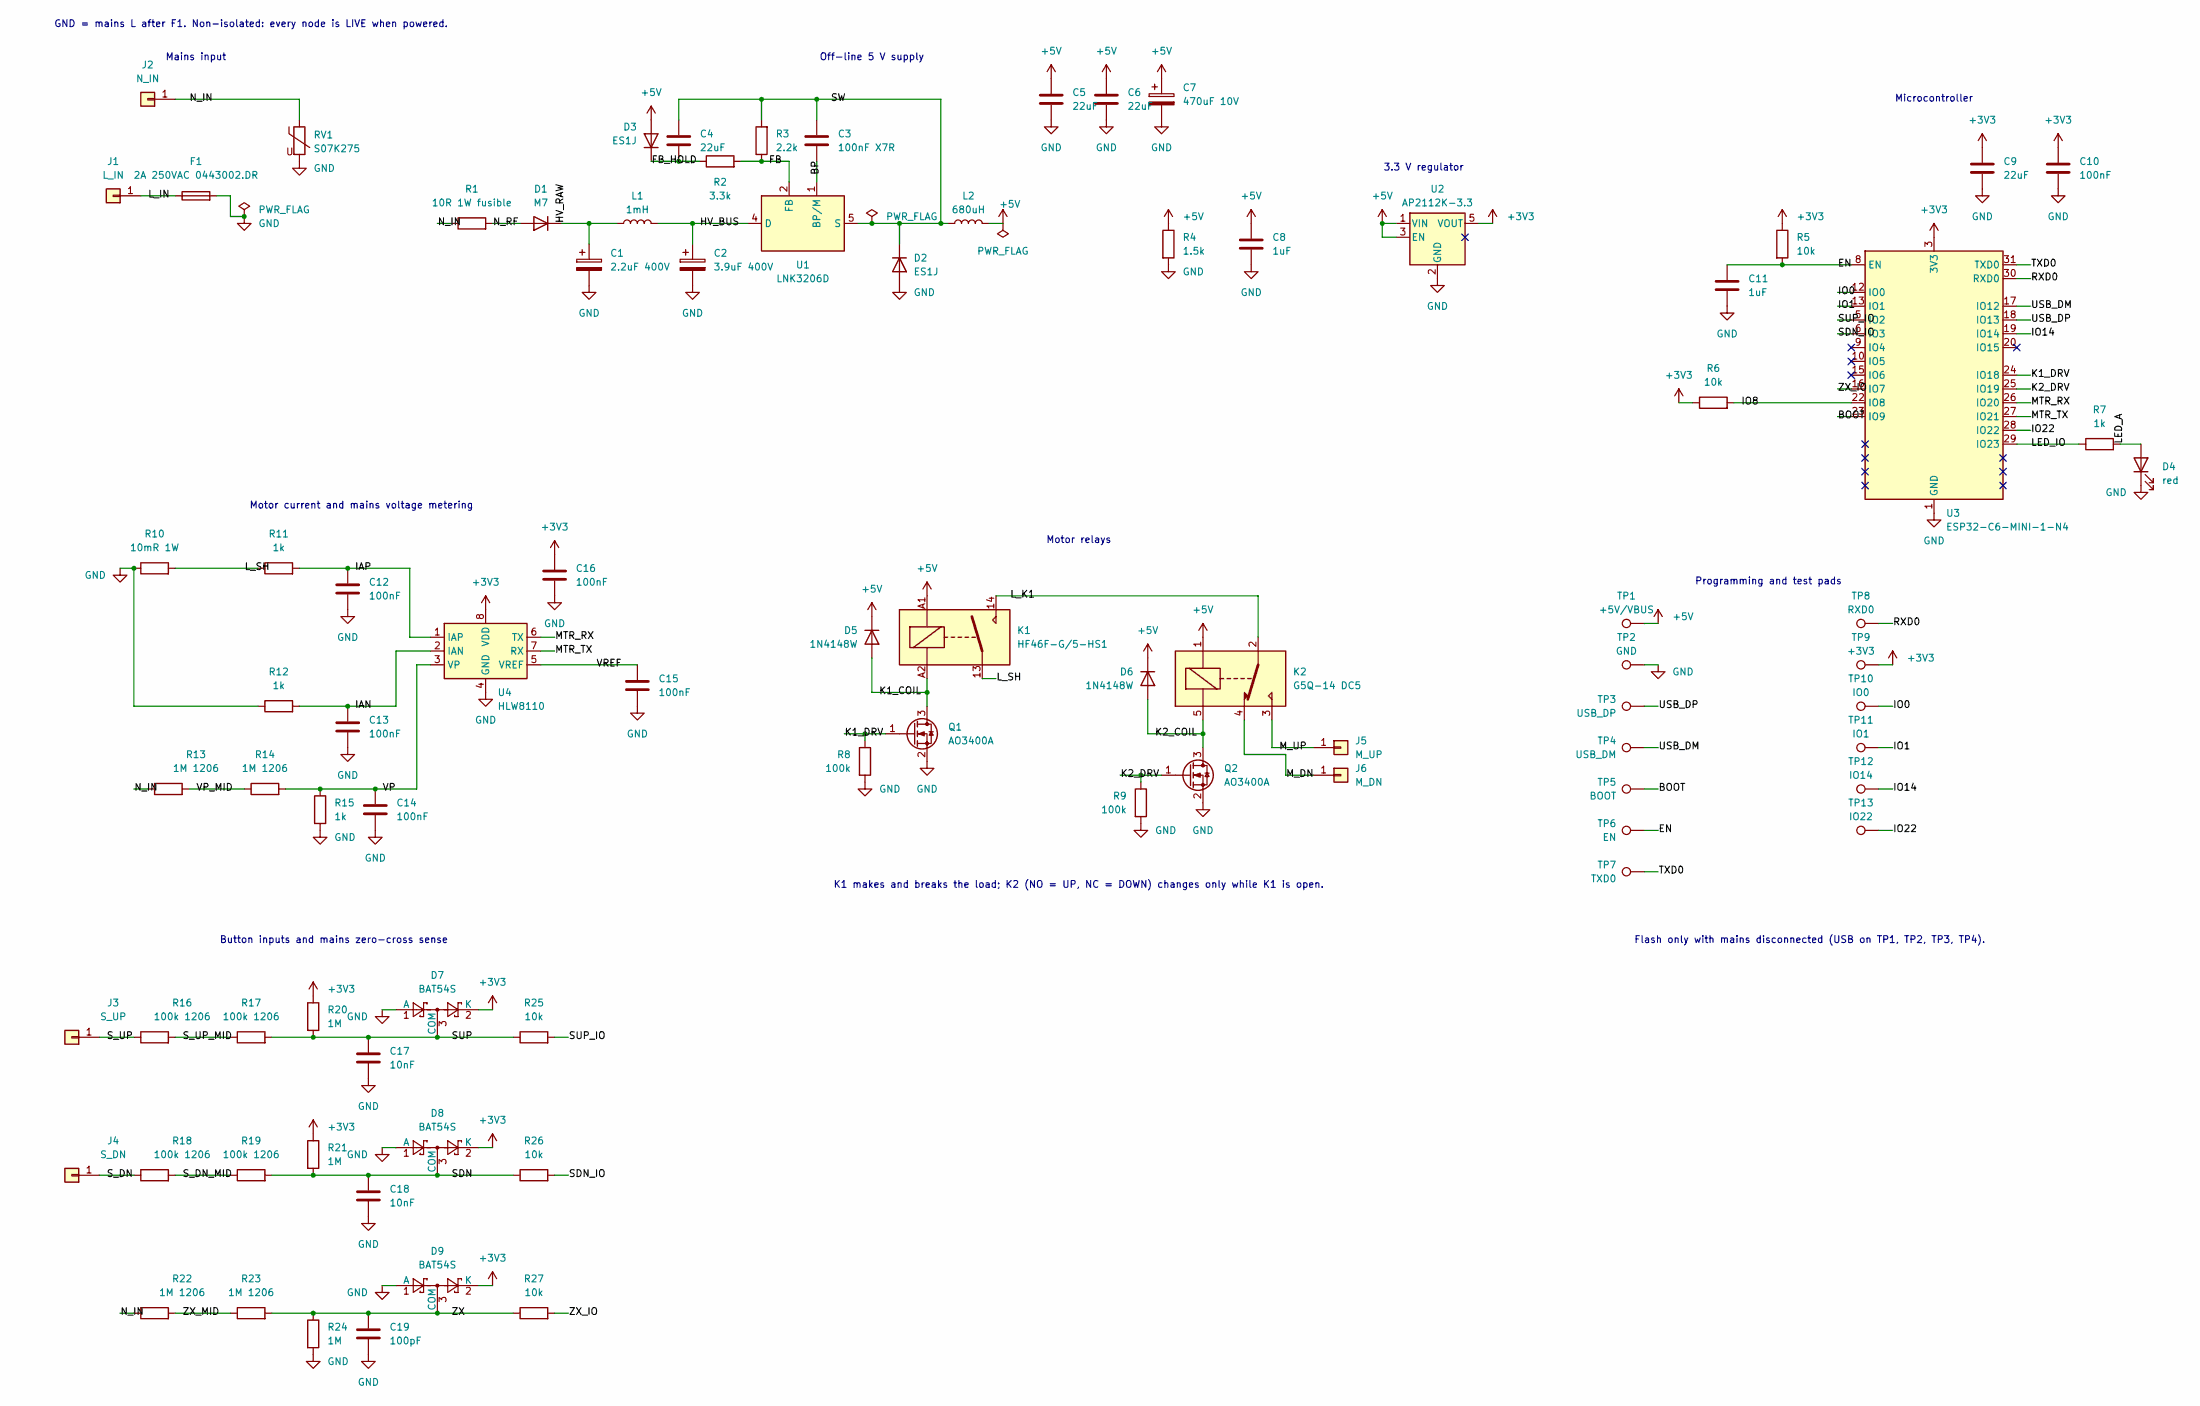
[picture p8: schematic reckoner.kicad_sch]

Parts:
C1: 2.2uF 400V; CP_Elec_6.3x9.9; LCSC C48970947
C2: 3.9uF 400V; CP_Elec_8x10; LCSC C33129636
C3: 100nF X7R; C_0603_1608Metric; LCSC C14663
C4, C9: 22uF; C_0805_2012Metric; LCSC C45783
C5, C6: 22uF; C_1206_3216Metric; LCSC C12891
C7: 470uF 10V; CP_Elec_8x10; LCSC C2693598
C8, C11: 1uF; C_0402_1005Metric; LCSC C52923
C10, C12, C13, C14, C15, C16: 100nF; C_0402_1005Metric; LCSC C1525
C17, C18: 10nF; C_0402_1005Metric; LCSC C15195
C19: 100pF; C_0402_1005Metric; LCSC C1546
D1: M7; D_SMA; LCSC C95872
D2, D3: ES1J; D_SMA; LCSC C86560
D4: red; LED_0603_1608Metric; LCSC C2286
D5, D6: 1N4148W; D_SOD-123; LCSC C81598
D7, D8, D9: BAT54S; SOT-23; LCSC C8592
F1: 2A 250VAC 0443002.DR; FUSE-SMD_L10.1-W3.1; LCSC C187538
J1: L_IN; SolderWire-0.75sqmm_1x01_D1.25mm_OD2.3mm
J2: N_IN; SolderWire-0.75sqmm_1x01_D1.25mm_OD2.3mm
J3: S_UP; SolderWire-0.75sqmm_1x01_D1.25mm_OD2.3mm
J4: S_DN; SolderWire-0.75sqmm_1x01_D1.25mm_OD2.3mm
J5: M_UP; SolderWire-0.75sqmm_1x01_D1.25mm_OD2.3mm
J6: M_DN; SolderWire-0.75sqmm_1x01_D1.25mm_OD2.3mm
K1: HF46F-G/5-HS1; Relay_SPST_Omron_G5NB; LCSC C165255
K2: G5Q-14 DC5; Relay_SPDT_Omron-G5Q-1; LCSC C397241
L1: 1mH; L_Taiyo-Yuden_NR-50xx; LCSC C5339706
L2: 680uH; IND-TH_BD9.5-P5.20-D0.6; LCSC C2924238
Q1, Q2: AO3400A; SOT-23; LCSC C20917
R1: 10R 1W fusible; R_Axial_DIN0309_L9.0mm_D3.2mm_P2.54mm_Vertical; LCSC C145951
R2: 3.3k; R_0402_1005Metric; LCSC C25890
R3: 2.2k; R_0402_1005Metric; LCSC C25879
R4: 1.5k; R_0603_1608Metric; LCSC C22843
R5, R6, R25, R26, R27: 10k; R_0402_1005Metric; LCSC C25744
R7: 1k; R_0603_1608Metric; LCSC C21190
R8, R9: 100k; R_0402_1005Metric; LCSC C25741
R10: 10mR 1W; R_1206_3216Metric; LCSC C105362
R11, R12, R15: 1k; R_0402_1005Metric; LCSC C11702
R13, R14, R22, R23: 1M 1206; R_1206_3216Metric; LCSC C17927
R16, R17, R18, R19: 100k 1206; R_1206_3216Metric; LCSC C17900
R20, R21, R24: 1M; R_0402_1005Metric; LCSC C26083
RV1: S07K275; RES-TH_L9.0-W4.6-P5.00-D0.6-S1.60; LCSC C1527389
TP1: +5V/VBUS; TestPoint_Pad_D1.0mm
TP2: GND; TestPoint_Pad_D1.0mm
TP3: USB_DP; TestPoint_Pad_D1.0mm
TP4: USB_DM; TestPoint_Pad_D1.0mm
TP5: BOOT; TestPoint_Pad_D1.0mm
TP6: EN; TestPoint_Pad_D1.0mm
TP7: TXD0; TestPoint_Pad_D1.0mm
TP8: RXD0; TestPoint_Pad_D1.0mm
TP9: +3V3; TestPoint_Pad_D1.0mm
TP10: IO0; TestPoint_Pad_D1.0mm
TP11: IO1; TestPoint_Pad_D1.0mm
TP12: IO14; TestPoint_Pad_D1.0mm
TP13: IO22; TestPoint_Pad_D1.0mm
U1: LNK3206D; PowerIntegrations_SO-8C; LCSC C2987730
U2: AP2112K-3.3; SOT-23-5; LCSC C51118
U3: ESP32-C6-MINI-1-N4; ESP32-C6-MINI-1; LCSC C5736265
U4: HLW8110; SOIC-8_3.9x4.9mm_P1.27mm; LCSC C970139

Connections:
+3V3: C9.1, C10.1, C16.1, D7.2 (K), D8.2 (K), D9.2 (K), R5.1, R6.1, R20.1, R21.1, TP9.1 (1_1), U2.5 (VOUT), U3.3 (3V3), U4.8 (VDD)
+5V: C5.1, C6.1, C7.1, C8.1, D3.2 (A), D5.1 (K), D6.1 (K), K1.A1, K2.1, L2.2, R4.1, TP1.1 (1_1), U2.1 (VIN), U2.3 (EN)
/BOOT: TP5.1 (1_1), U3.23 (IO9)
/BP: C3.1, U1.1 (BP/M)
/EN: C11.1, R5.2, TP6.1 (1_1), U3.8 (EN)
/FB: R2.2, R3.1, U1.2 (FB)
/FB_HOLD: C4.1, D3.1 (K), R2.1
/HV_BUS: C2.1, L1.2, U1.4 (D)
/HV_RAW: C1.1, D1.1 (K), L1.1
/IAN: C13.1, R12.2, U4.2 (IAN)
/IAP: C12.1, R11.2, U4.1 (IAP)
/IO0: TP10.1 (1_1), U3.12 (IO0)
/IO1: TP11.1 (1_1), U3.13 (IO1)
/IO8: R6.2, U3.22 (IO8)
/IO14: TP12.1 (1_1), U3.19 (IO14)
/IO22: TP13.1 (1_1), U3.28 (IO22)
/K1_COIL: D5.2 (A), K1.A2, Q1.3 (D)
/K1_DRV: Q1.1 (G), R8.1, U3.24 (IO18)
/K2_COIL: D6.2 (A), K2.5, Q2.3 (D)
/K2_DRV: Q2.1 (G), R9.1, U3.25 (IO19)
/LED_A: D4.2 (A), R7.2
/LED_IO: R7.1, U3.29 (IO23)
/L_IN: F1.1, J1.1 (Pin_1_1)
/L_K1: K1.14, K2.2
/L_SH: K1.13, R10.2, R11.1
/MTR_RX: U3.26 (IO20), U4.6 (TX)
/MTR_TX: U3.27 (IO21), U4.7 (RX)
/M_DN: J6.1 (Pin_1_1), K2.4
/M_UP: J5.1 (Pin_1_1), K2.3
/N_IN: J2.1 (Pin_1_1), R1.1, R13.1, R22.1, RV1.1
/N_RF: D1.2 (A), R1.2
/RXD0: TP8.1 (1_1), U3.30 (RXD0)
/SDN: C18.1, D8.3 (COM), R19.2, R21.2, R26.1
/SDN_IO: R26.2, U3.6 (IO3)
/SUP: C17.1, D7.3 (COM), R17.2, R20.2, R25.1
/SUP_IO: R25.2, U3.5 (IO2)
/SW: C3.2, C4.2, D2.1 (K), L2.1, R3.2, U1.5 (S), U1.6 (S), U1.7 (S), U1.8 (S)
/S_DN: J4.1 (Pin_1_1), R18.1
/S_DN_MID: R18.2, R19.1
/S_UP: J3.1 (Pin_1_1), R16.1
/S_UP_MID: R16.2, R17.1
/TXD0: TP7.1 (1_1), U3.31 (TXD0)
/USB_DM: TP4.1 (1_1), U3.17 (IO12)
/USB_DP: TP3.1 (1_1), U3.18 (IO13)
/VP: C14.1, R14.2, R15.1, U4.3 (VP)
/VP_MID: R13.2, R14.1
/VREF: C15.1, U4.5 (VREF)
/ZX: C19.1, D9.3 (COM), R23.2, R24.1, R27.1
/ZX_IO: R27.2, U3.16 (IO7)
/ZX_MID: R22.2, R23.1
GND: C1.2, C2.2, C5.2, C6.2, C7.2, C8.2, C9.2, C10.2, C11.2, C12.2, C13.2, C14.2, C15.2, C16.2, C17.2, C18.2, C19.2, D2.2 (A), D4.1 (K), D7.1 (A), D8.1 (A), D9.1 (A), F1.2, Q1.2 (S), Q2.2 (S), R4.2, R8.2, R9.2, R10.1, R12.1, R15.2, R24.2, RV1.2, TP2.1 (1_1), U2.2 (GND), U3.1 (GND), U3.2 (GND), U3.11 (GND), U3.14 (GND), U3.36 (GND), U3.37 (GND), U3.38 (GND), U3.39 (GND), U3.40 (GND), U3.41 (GND), U3.42 (GND), U3.43 (GND), U3.44 (GND), U3.45 (GND), U3.46 (GND), U3.47 (GND), U3.48 (GND), U3.49 (GND), U3.50 (GND), U3.51 (GND), U3.52 (GND), U3.53 (GND), U4.4 (GND)

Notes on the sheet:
Microcontroller
Motor current and mains voltage metering
K1 makes and breaks the load; K2 (NO = UP, NC = DOWN) changes only while K1 is open.
Button inputs and mains zero-cross sense
3.3 V regulator
Mains input
Programming and test pads
Off-line 5 V supply
GND = mains L after F1. Non-isolated: every node is LIVE when powered.
Motor relays
Flash only with mains disconnected (USB on TP1, TP2, TP3, TP4).

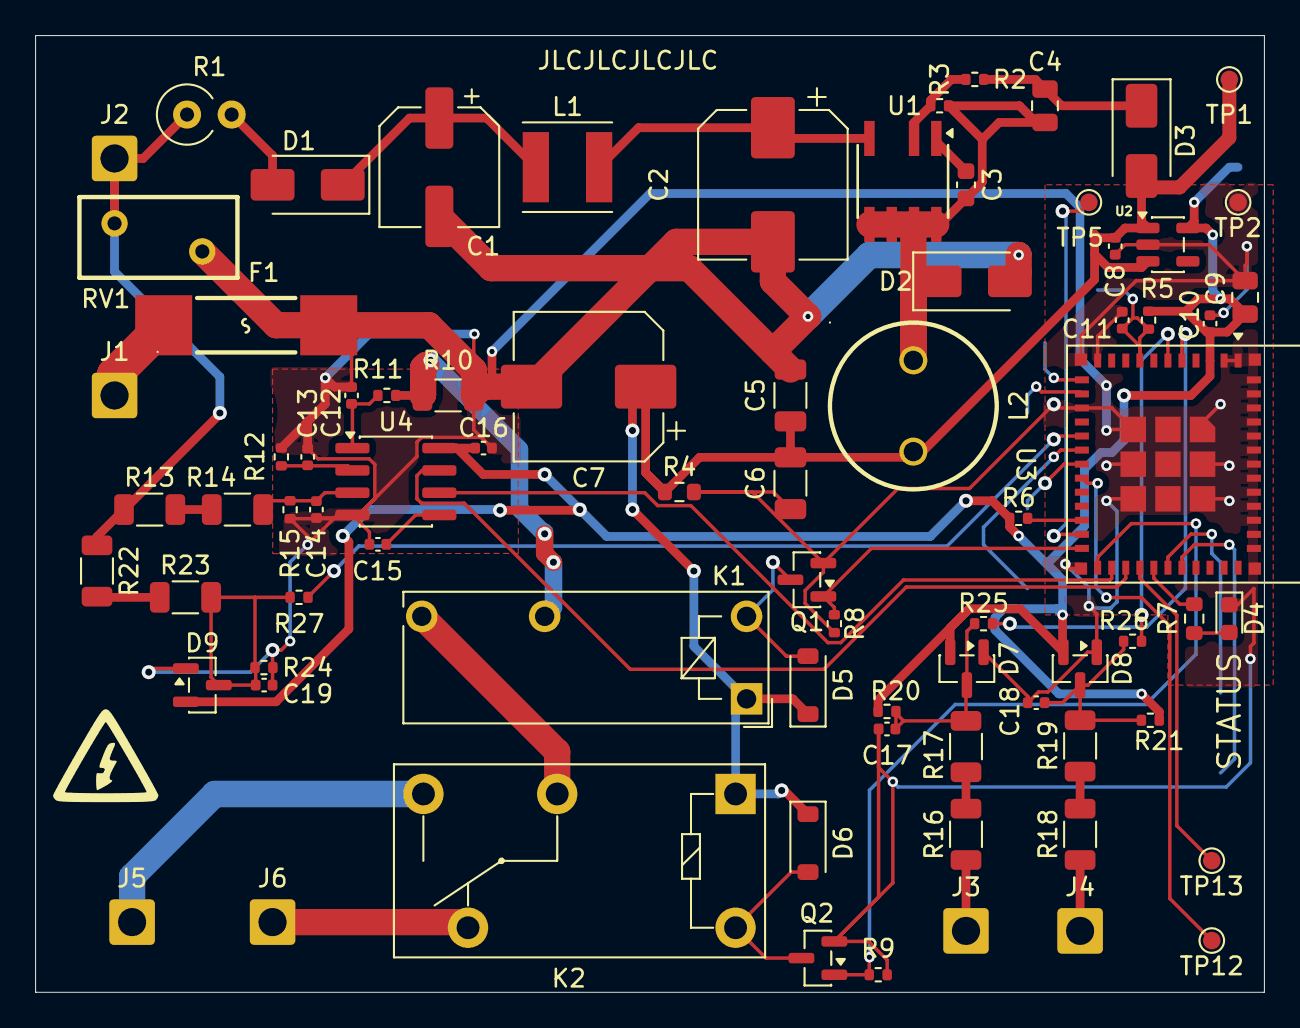
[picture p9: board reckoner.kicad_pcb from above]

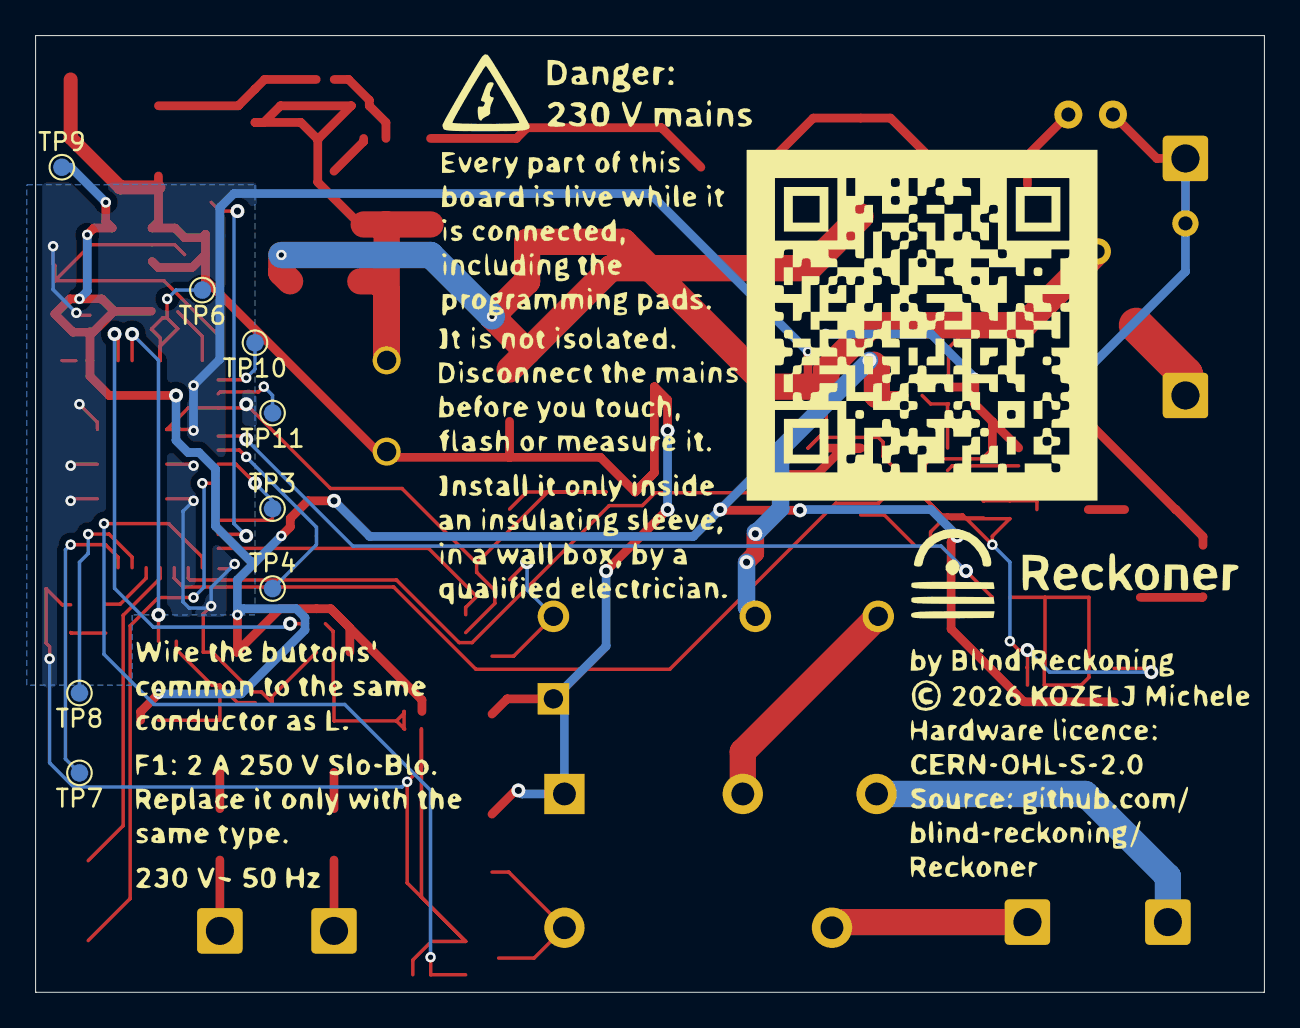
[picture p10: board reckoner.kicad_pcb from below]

Board: 2 copper layers, 70.0 x 54.5 mm, 86 parts (8 on the bottom side), 51 nets.

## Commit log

2026-09-27 Initial commit
    Added all of the initial files to the repo.
    [reckoner.kicad_sch]
2026-10-01 Design the Reckoner: requirements, BOM and wired schematic
    [bom.csv, reckoner.kicad_sch]
2026-10-02 Add README with project overview and mains safety warnings
    - what the Reckoner does and how it works, with the K1/K2 interlock
    - danger banner, safety signs and badges for the 230 VAC hazard
    - safety rules (never, before you install, bench testing) and a
    disclaimer
    - docs/images: banner, safety signs, schematic, interlock and wiring
    images
2026-10-02 Add licences: CERN-OHL-S-2.0 for hardware, CC BY-SA 4.0 for docs
    - LICENSE: CERN Open Hardware Licence v2, strongly reciprocal
    (canonical text from ohwr.org), for PCB/, CAD/ and bom.csv
    - LICENSE-DOCS: CC BY-SA 4.0 legal code, for the README and docs/
    - README: licence section and badges; both licences apply
    retroactively to every earlier commit; CERN hardware notice with
    the source location; firmware licence left for later; name, logos,
    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
2026-10-03 Change C2 to FOLLON 3.9 µF 400 V for ripple current
    The LNK3206's drain pulses put about 45 mA RMS into C2, 239 % of the
    Honor 2.2 µF part's rating. The FOLLON EFVD400ADA3R9M08B0 (C33129636,
    8 x 10.5 mm, CP_Elec_8x10) runs at about 49 %. C1 is unchanged.
    Hold-up in the README corrected to the worst-case figure.
    [bom.csv, reckoner.kicad_sch]
2026-10-03 Use LCSC footprints for F1, RV1 and L2
    [bom.csv, reckoner.kicad_sch]
2026-10-03 Set up the board: net classes, JLCPCB constraints, fixed courtyards
    [reckoner.kicad_pcb]
2026-10-03 Place and route the board
    [reckoner.kicad_pcb, reckoner.kicad_sch]
2026-10-04 Add silkscreen artwork: mains warnings, licence and QR code
    [reckoner.kicad_pcb]
2026-10-04 Add production files for JLCPCB
    [bom.csv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]
2026-10-04 Split the BOM between LCSC and Digi-Key
    [bom-digikey.csv, bom-lcsc.csv, bom.csv]
2026-10-04 Move the BOM into BOM/, add the order cost and update the README
    [Reckoner-LCSC.xls, Reckoner-digikey.xlsx, bom.csv]
